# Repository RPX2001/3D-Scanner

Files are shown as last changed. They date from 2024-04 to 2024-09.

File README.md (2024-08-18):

# 3D Scanner Project

This repository contains the design and implementation of a 3D scanner using an ATmega328P microcontroller, NEMA 17 stepper motors, and stepper drivers. The goal of this project is to capture a point cloud of a 3D object, transmit the data to a computer as serial data, and map those points using software.

## Project Overview
Our 3D scanner project aims to design and build a machine capable of scanning an object and generating a 3D map of it. The scanner primarily comprises two parts: a linear Z-axis motion slider and a turntable. The object to be scanned is placed on the turntable, which rotates during scanning. After each full rotation, the Z-axis slider raises the ToF sensor slightly, and the process repeats. Distance measurements from the ToF sensor are sent to a PC in real-time via serial communication, stored in a .txt file, and used to generate a 3D point cloud map of the scanned object.

## Project Components
- **Microcontroller**: ATmega328P
- **Stepper Motors**: NEMA 17
- **Stepper Motor Drivers**: TB6600
- **ToF Sensor**: VL53L0X
- **Voltage Regulator**: LM7805
- **USB to Serial Converter**: CH340C
- **Turntable and Z-axis Slider**: Custom mechanical parts designed in SolidWorks

## Electronic Design

### Component Selection

- **Microcontroller (ATmega328P)**: Chosen for its reliability, compact size, and capability to handle multiple inputs efficiently. It is programmed via a USB connection using the CH340C IC.
- **Stepper Motors (NEMA 17)**: Selected for their high torque and compatibility with 12V power supply. Specifications include 76 oz*in torque, 1.8° step angle, and 1.68A/phase peak current.
- **Stepper Motor Drivers (TB6600)**: Supports a wide range of power inputs (9-42VDC) and can output 4A peak current. Features include speed and direction control, microstep settings, and high-speed optocoupler isolation.
- **ToF Sensor (VL53L0X)**: Provides accurate distance measurements for scanning.
- **Voltage Regulator (LM7805)**: Converts 12V input to a stable 5V output to power the microcontroller and sensor.

### PCB Design
The PCB design integrates the microcontroller, voltage regulator, stepper motor drivers, and USB to serial converter. SMD components are used to minimize space. The design includes necessary capacitors for the LM7805, signal routing for stepper motor control, and connectors for the ToF sensor and stepper motors.

## Mechanical Design
The mechanical design includes a 14cm diameter turntable and a Z-axis slider mechanism. Components such as smooth shafts, screw shafts, and couplers ensure precise linear motion. The enclosure houses the PCB, stepper drivers, and motors, providing a compact and durable structure.

## Software Implementation
### Arduino Code
The Arduino code controls the stepper motors and reads distance values from the ToF sensor. It uses direct port manipulation and register-level programming for efficient motor control.

### Functionality

1. **Object Placement:** The object to be scanned is placed on a turntable.
2. **Rotation and Scanning:** The turntable rotates the object while the distance sensor captures measurements along the Z-axis.
3. **Data Transmission:** The ATmega328P microcontroller collects the distance measurements and transmits the data to a computer via serial communication.
4. **Point Cloud Mapping:** Software on the computer receives the serial data and maps the points to create a 3D representation of the object.

### PCB 

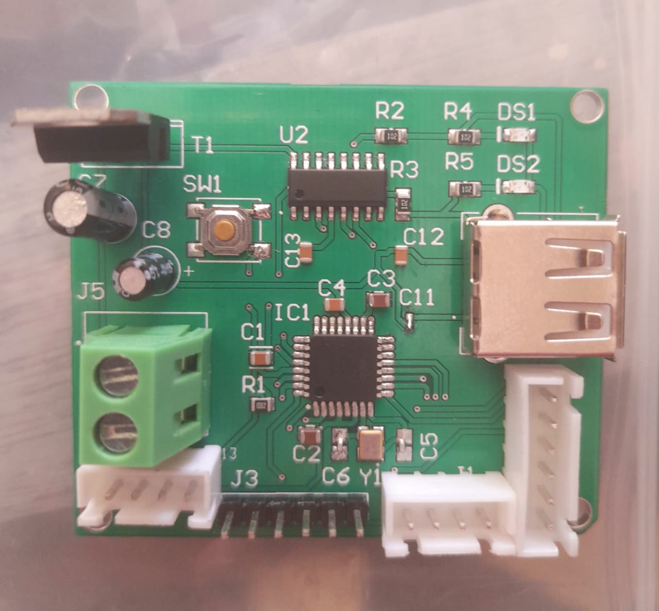
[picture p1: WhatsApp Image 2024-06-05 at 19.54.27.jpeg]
PCB


### Enclosure

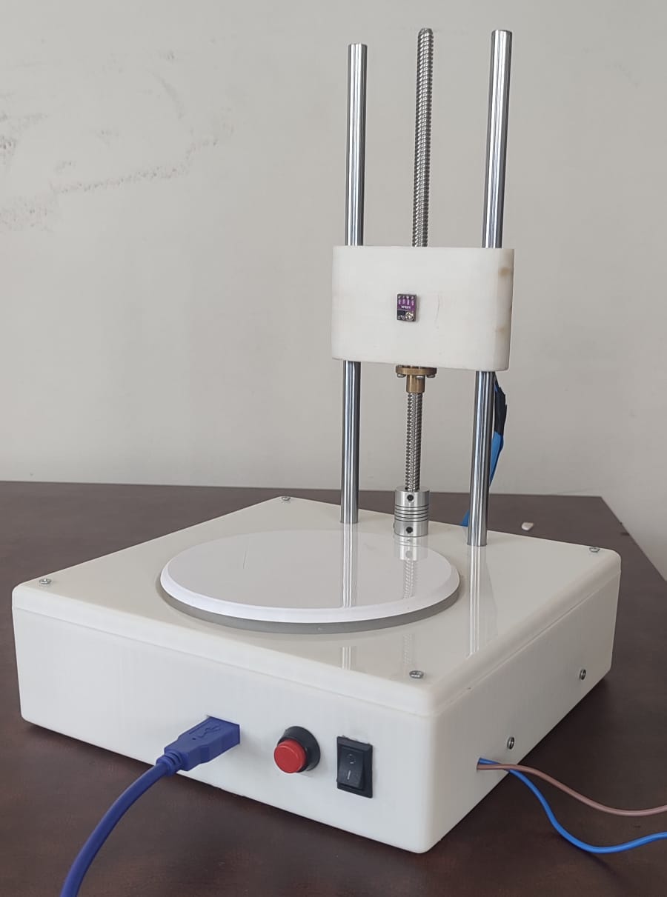
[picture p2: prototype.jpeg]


### System Integration

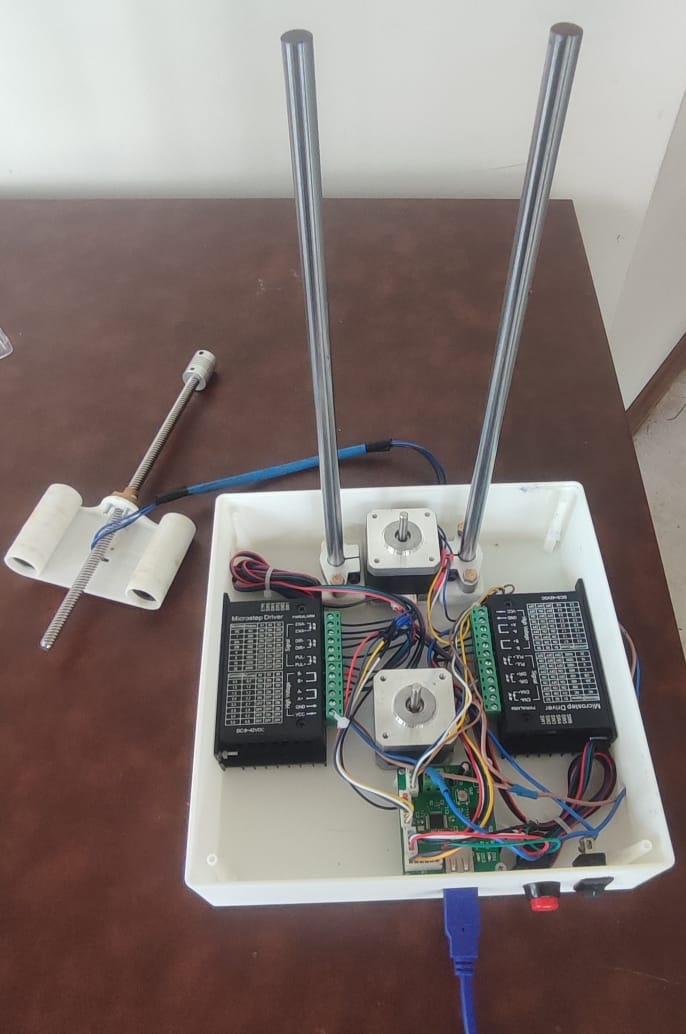
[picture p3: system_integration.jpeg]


## Contributors

- [Samudra Uduwaka](https://github.com/samudra-uduwaka)

## License

This project is licensed under the [MIT License](LICENSE).

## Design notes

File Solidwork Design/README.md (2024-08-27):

## Solidwork Design

The Solidwork design for our project, 3D Scanner is mainly comprised of 3 parts:

- Main Body
- Tray lid
- Turnable table
- Connector part

Used platform: Solidworks

All the sub main parts of the design are designed so that they are moldable for the large scale producability and, for the ease of testing we decided for 3D printing the parts.

Enclosure

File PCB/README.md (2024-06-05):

# PCB Design of the 3D scanner

This repository contains the design and implementation of a 3D scanner using an ATmega328P microcontroller, NEMA 17 stepper motors, and stepper drivers. The project aims to capture a point cloud of a 3D object and transmit the data to a computer as serial data for mapping those points using software.

### PCB 
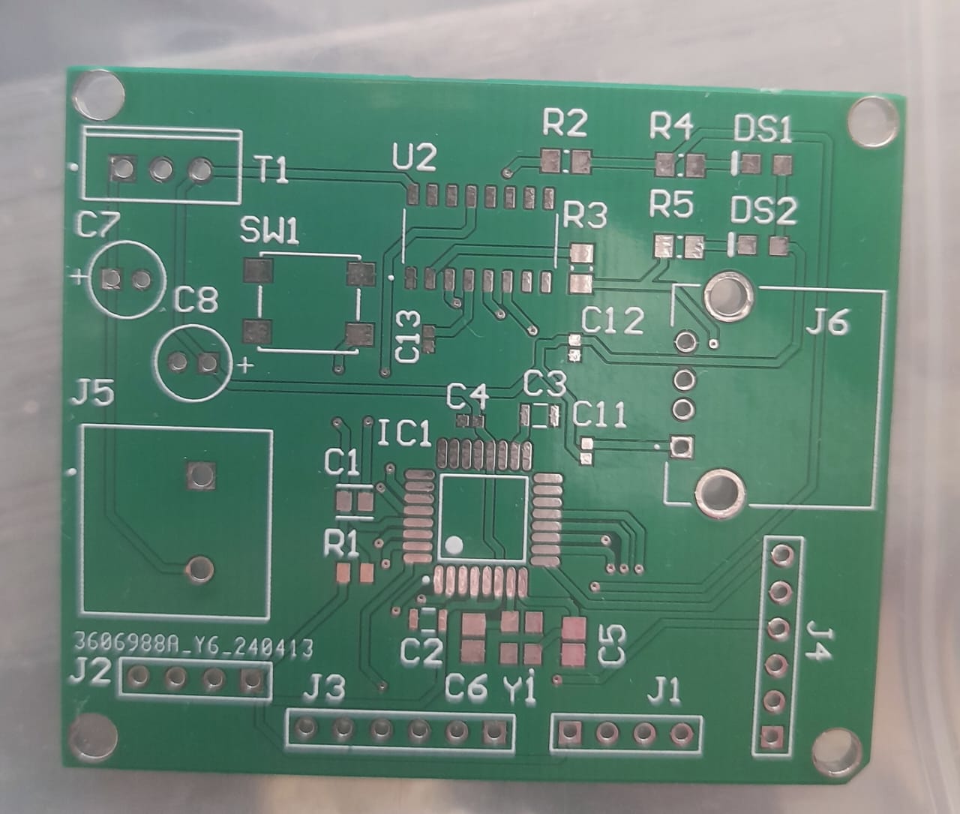
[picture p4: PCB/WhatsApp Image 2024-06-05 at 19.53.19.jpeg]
PCB


### Components

- **Microcontroller:** ATmega328P (SMD)
- **USB to Serial Chip:** CH340C
- **Stepper Motors:** NEMA 17
- **Stepper Drivers:** (Specify model, e.g., A4988 or DRV8825)
- **Distance Sensor:** ToF sensor (using SCL and SDA pins)
- **Mechanical Design:** Smooth and screw shafts for precision movement
- **PCB Layout:** Designed using SMD components
  
### Bill of Materials

| Comment | Description | Designator | Footprint | LibRef | Quantity |
|---|---|---|---|---|---|
| 0.1uF | Multilayer Ceramic Capacitor 0.1uF 10V 10% SMD 0805 T/R | C1 | FP-0805-L_2_0_0_1-W_1_25-IPC_C | CMP-14477-004636-2 | 1 |
| 10uF | Cap Ceramic 10uF 25V X7S 10% Pad SMD 0805 +125°C Automotive T/R | C2, C3 | FP-CGA4J-IPC_C | CMP-08246-001526-1 | 2 |
| 100nF | Chip Capacitor, 100nF, +/-10%, 16V, -55 to 125 degC, 0402 (1005 Metric) | C4, C11-C13| CAPC1050X55X23ML05T13 | CMP-2000-05439-1 | 4 |
| 10uF (Electrolytic)| Aluminum Electrolytic Capacitor, 10uF, +/-20%, 50V, -40 to 85 degC | C7, C8 | CAPPR55-200-1100X500X1200 | CMP-001-00025-7 | 2 |
| Green LED | Chip LED, Green, 2.2V, -40 to 85 degC, 2-Pin SMD, Pb-Free, Tape and Reel | DS1, DS2 | AVAG-HSMX-C170_V | CMP-2000-05062-1 | 2 |
| ATmega328P | 8-bit AVR Microcontroller, 32KB Flash, 1KB EEPROM, 2KB SRAM, 32-pin TQFP | IC1 | 32A_M | CMP-0095-00269-2 | 1 |
| Header 4-Pin  | Header, 4-Pin | J1, J2 | HDR1X4 | Header 4 | 2 |
| Header 6-Pin  | Header, 6-Pin | J3, J4 | HDR1X6 | Header 6 | 2 |
| Terminal Block| PC Terminal Block, Pitch 6.35 mm, 1 x 2 Position, Height 21.5 mm | J5 | PHOE-1714955_V | CMP-2000-05797-1 | 1 |
| USB Connector | USB 2.0 Interface, Type A | J6 | SAMTEC_USB-A-S-X-X-TH | USB-A-S-X-X-TH | 1 |
| 10k Resistor  | Chip Resistor, 10k Ohm, +/-1%, 125 mW, -55 to 155 degC, 0805 (2012 Metric)  | R1 | RESC2013X60X40LL15T20 | CMP-2001-04472-1 | 1 |
| 1k Resistor | Chip Resistor, 1k Ohm, +/-1%, 125 mW, -55 to 155 degC, 0805 (2012 Metric) | R2, R3, R4, R5 | RESC2013X60X35ML10T20 | CMP-2100-03671-1 | 4 |
| Switch | Push Button Switch | SW1 | WS-TASV_L6W6H2.5_4304x30258x6 | CMP-1455-00007-2 | 1 |
| 5V Regulator  | Positive Voltage Regulator, 5V, 1A, 0 to 125 degC, 3-Pin TO-220, RoHS, Tube | T1 | FAIR-TO-220-3 | CMP-2000-04937-1 | 1 |
| USB to Serial | USB to Serial Chip | U2 | SOIC127P600X180-16N | CH340C | 1 |
| Crystal | Quartz Crystal | Y1 | WE-XTAL_CFPX-180 | CMP-03913-116876469-1 | 1 |

### Block Diagrams and Schematics

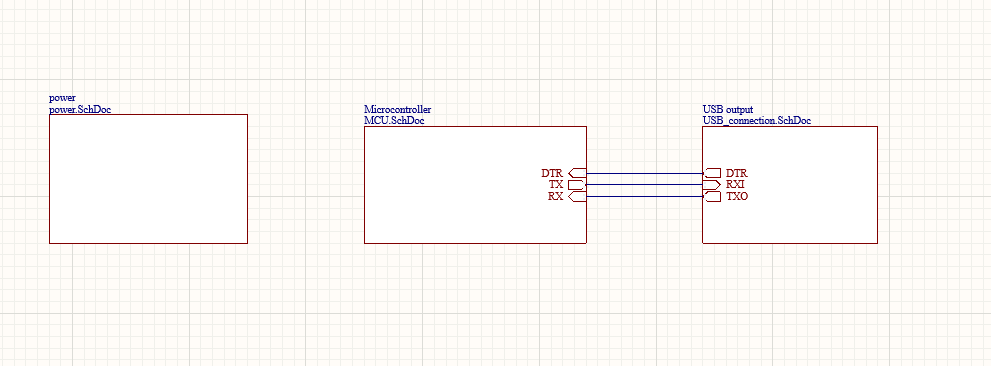
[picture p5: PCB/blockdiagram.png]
Functional Block Diagram


### Microcontroller Unit

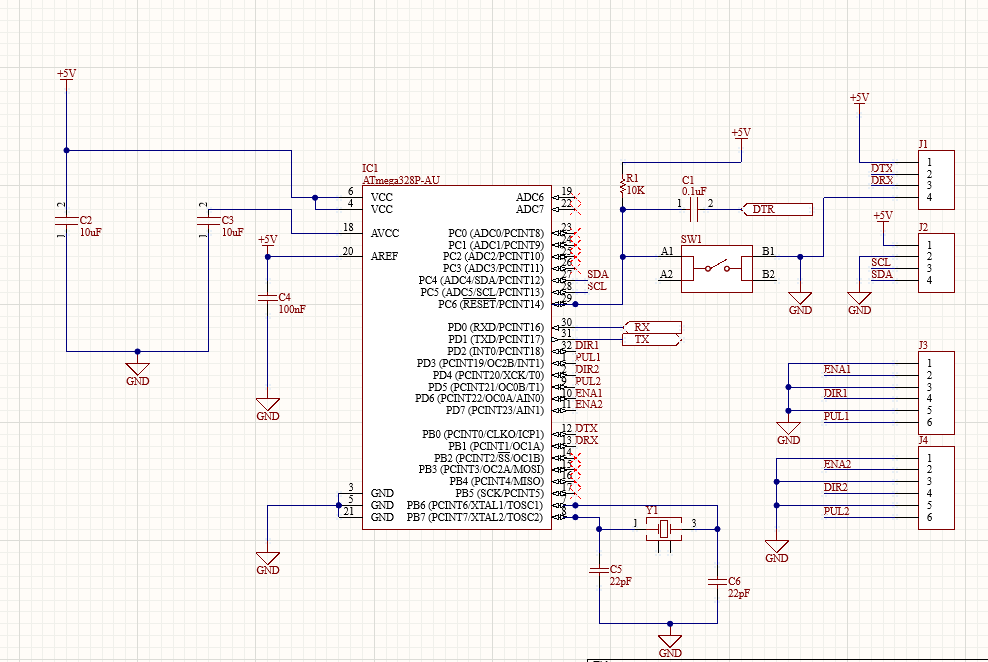
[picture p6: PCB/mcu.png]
microcontroller unit


### USB Connection

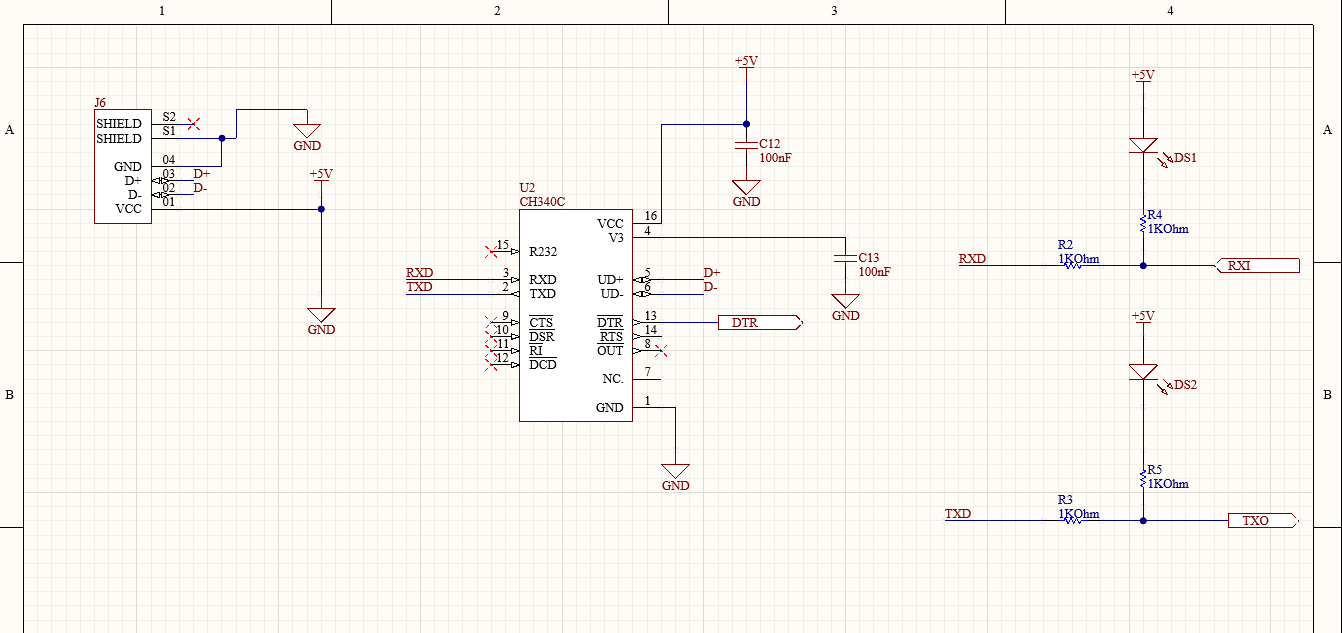
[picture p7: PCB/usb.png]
USB


### Power Regulation

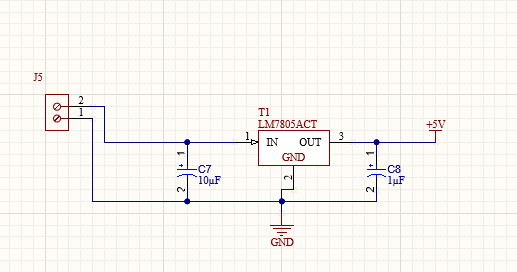
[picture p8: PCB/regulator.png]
Power


## PCB Layout

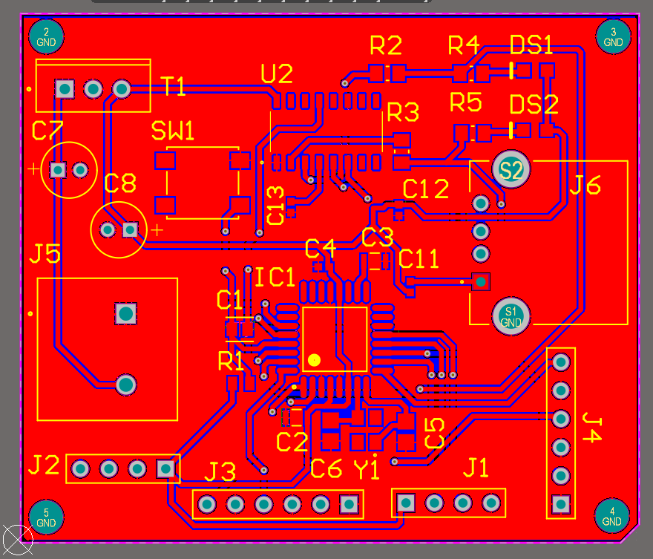
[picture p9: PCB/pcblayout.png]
PCB Layout


## 3D Design

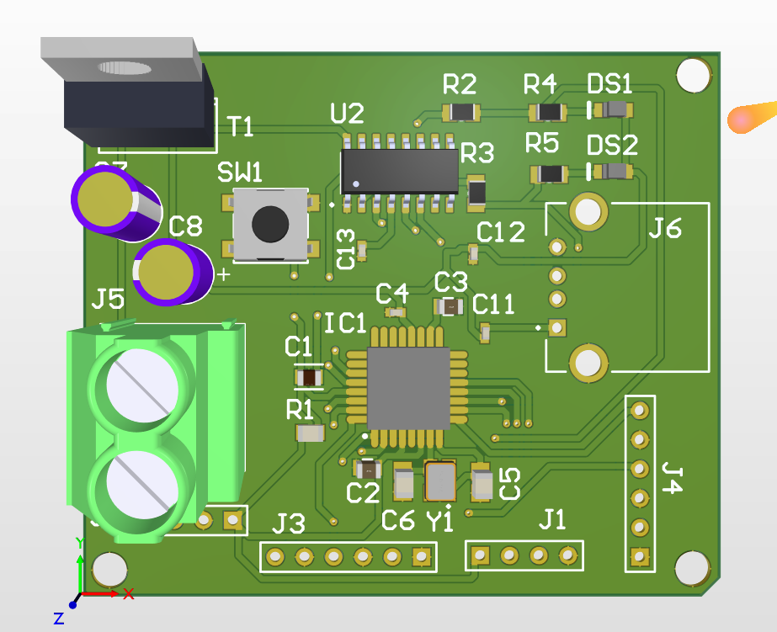
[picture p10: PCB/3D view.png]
3D design


## License

This project is licensed under the MIT License. See the [LICENSE](LICENSE) file for details.

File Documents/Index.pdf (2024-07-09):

Index | Name | Signature
210451U | Pathirana R. P. S.
210663V | Uduwaka S. S.

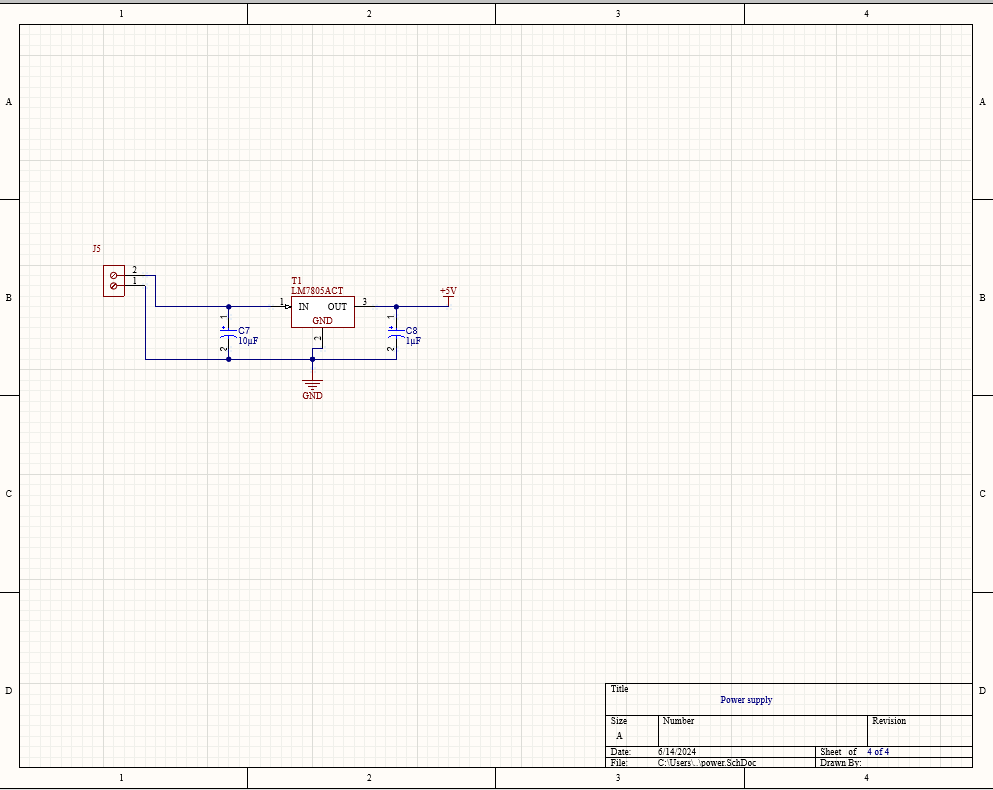
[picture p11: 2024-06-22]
power.png

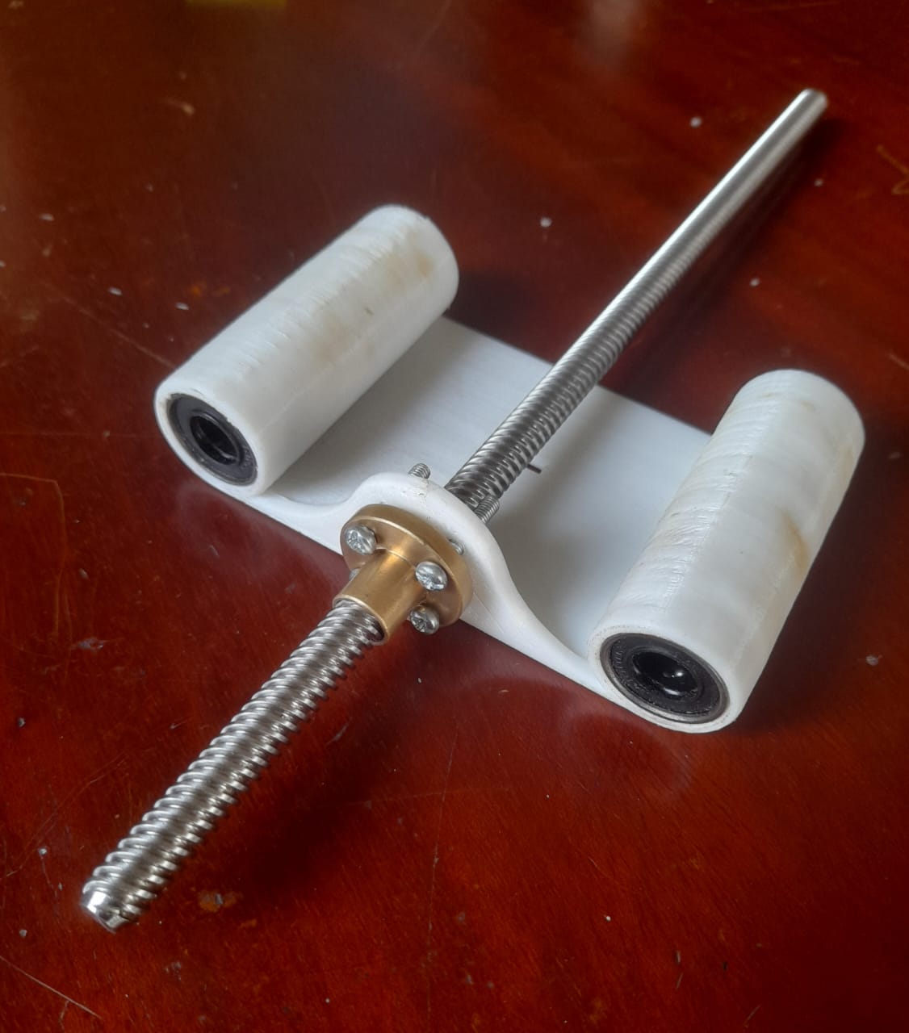
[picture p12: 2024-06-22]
connector.jpeg

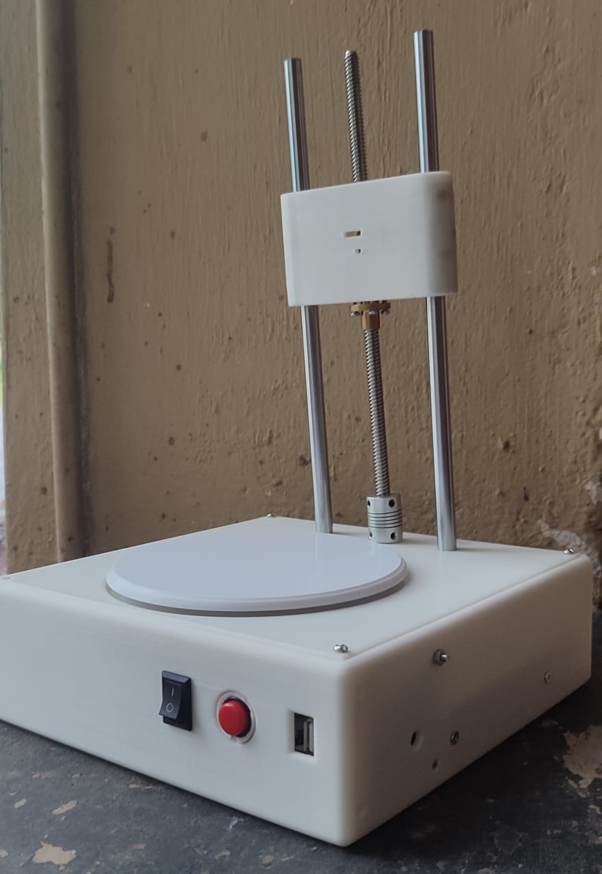
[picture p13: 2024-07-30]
final.jpeg

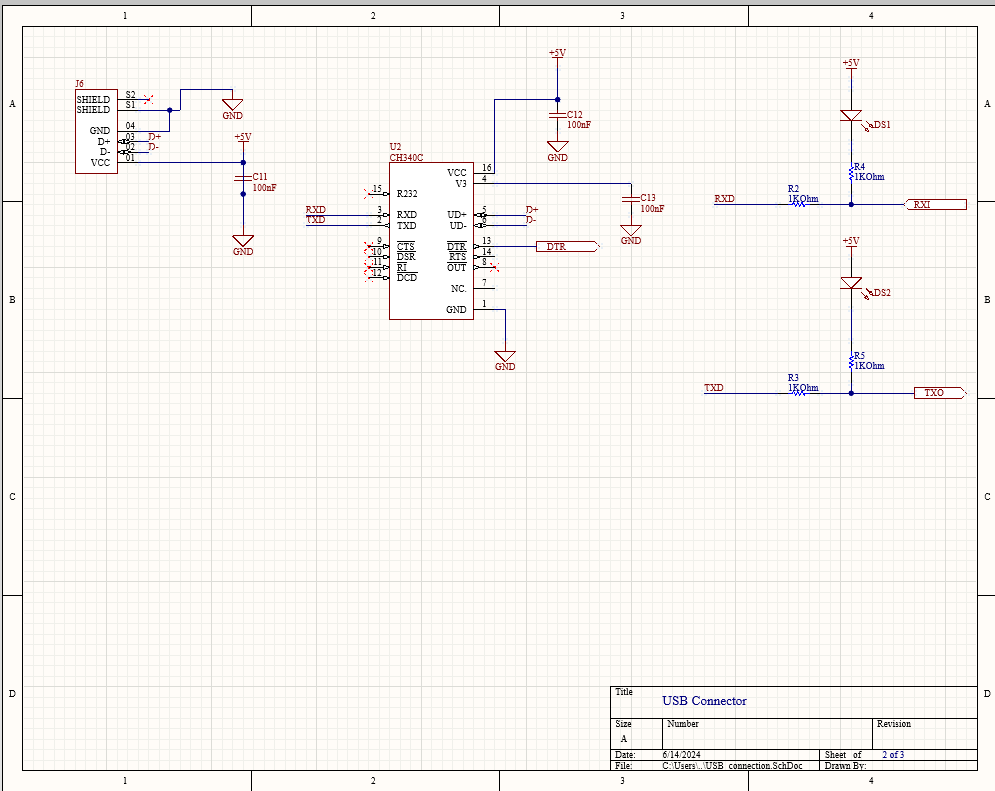
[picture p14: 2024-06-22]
usb.png

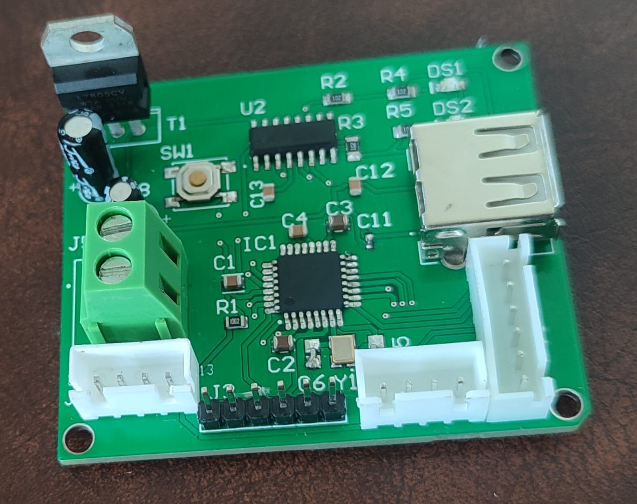
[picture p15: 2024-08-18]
pcb.jpeg

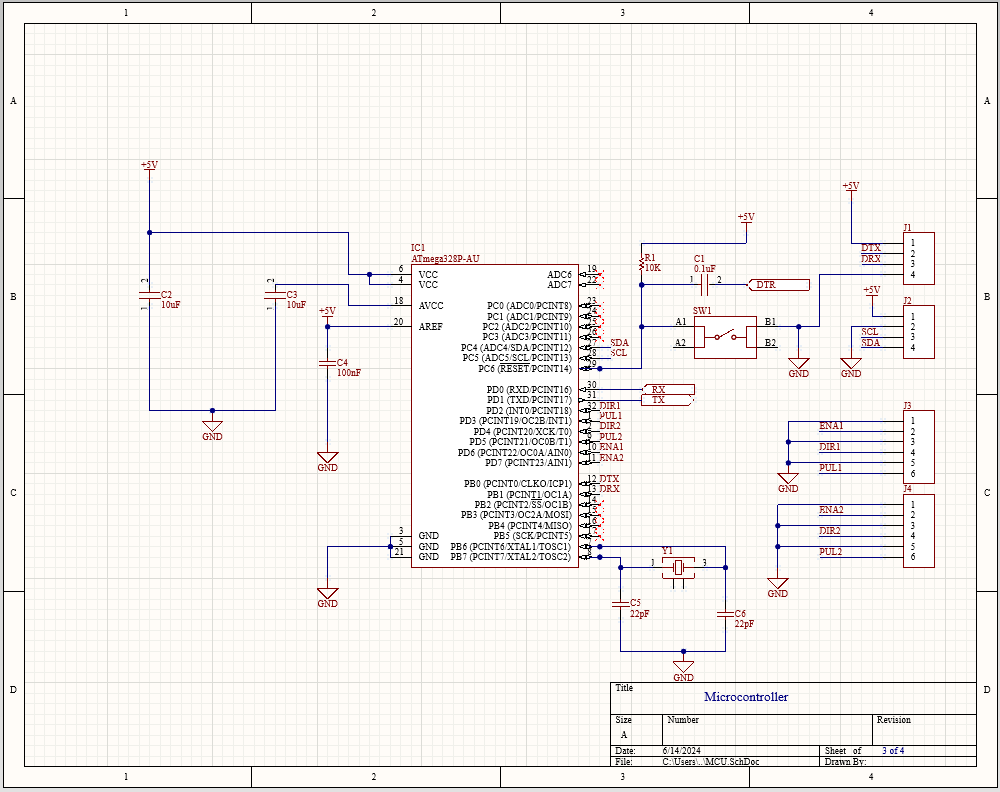
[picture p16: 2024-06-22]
mcu.png

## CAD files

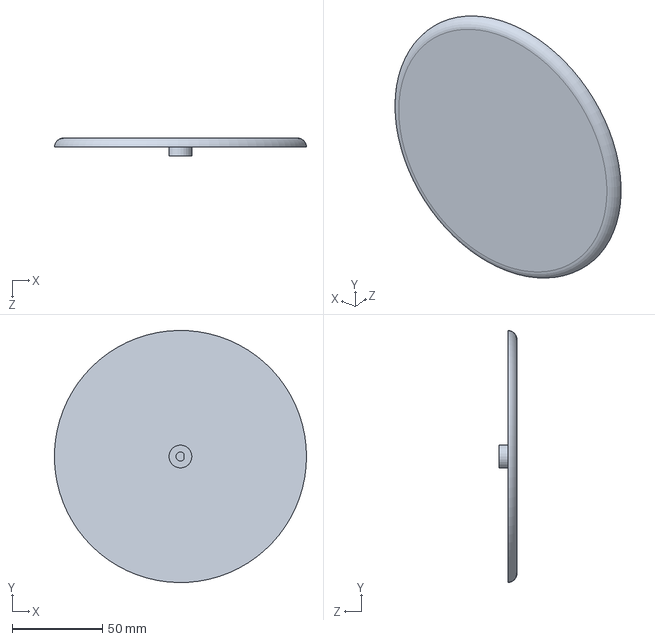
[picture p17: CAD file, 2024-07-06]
Solidwork Design/Part4_Assem2.SLDPRT
139.9 x 140.0 x 10.0 mm

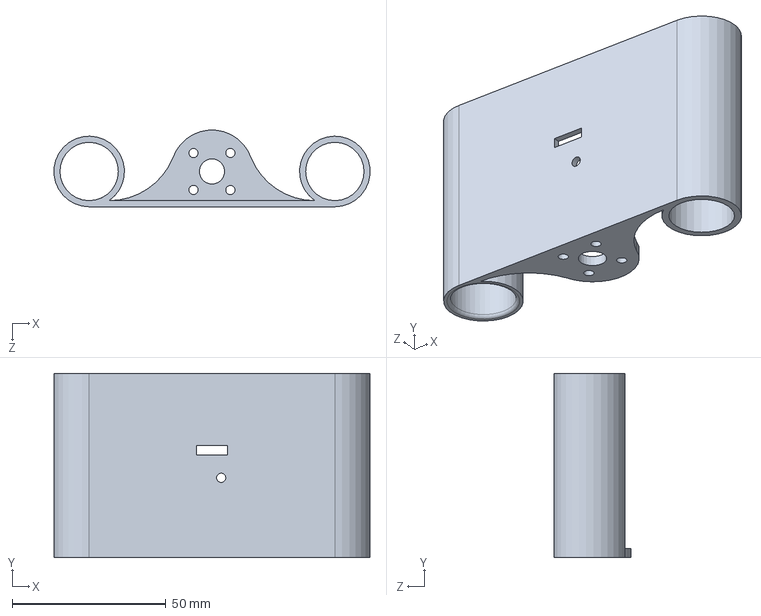
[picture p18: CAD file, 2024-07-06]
Solidwork Design/Part1 (1).SLDPRT
102.9 x 60.0 x 24.9 mm

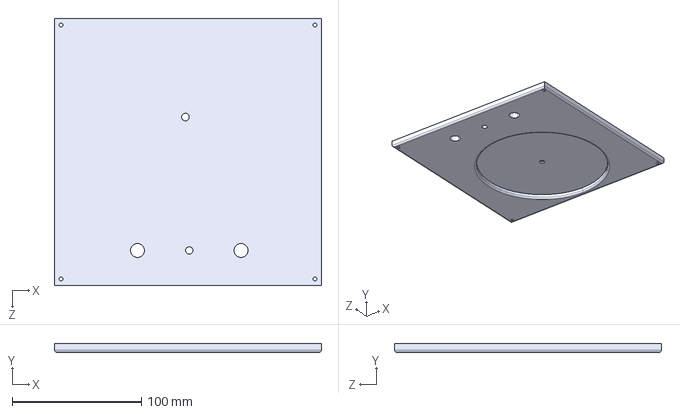
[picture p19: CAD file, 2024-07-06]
Solidwork Design/TrayLid.STEP
206.2 x 7.00 x 206.2 mm

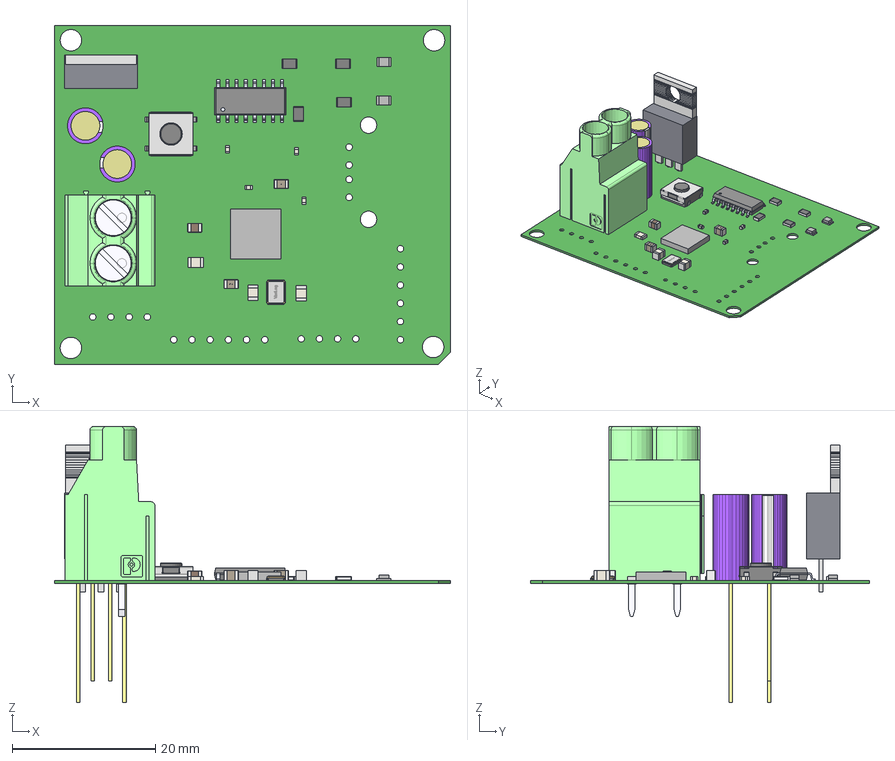
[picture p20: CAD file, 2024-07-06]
Solidwork Design/3Dscanner.step
55.2 x 47.2 x 38.5 mm
Extruded x 73
Pins
Cover
base
top_cover
Mid_Body x 4
Open_CASCADE_STEP_translator_6.8_3.2.1 x 8
Mark x 4
mkds_5-2-6.35
side x 4
TDK_Logo x 2
Terminals
Electrode
Taiyo

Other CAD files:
Solidwork Design/TrayLid.SLDPRT

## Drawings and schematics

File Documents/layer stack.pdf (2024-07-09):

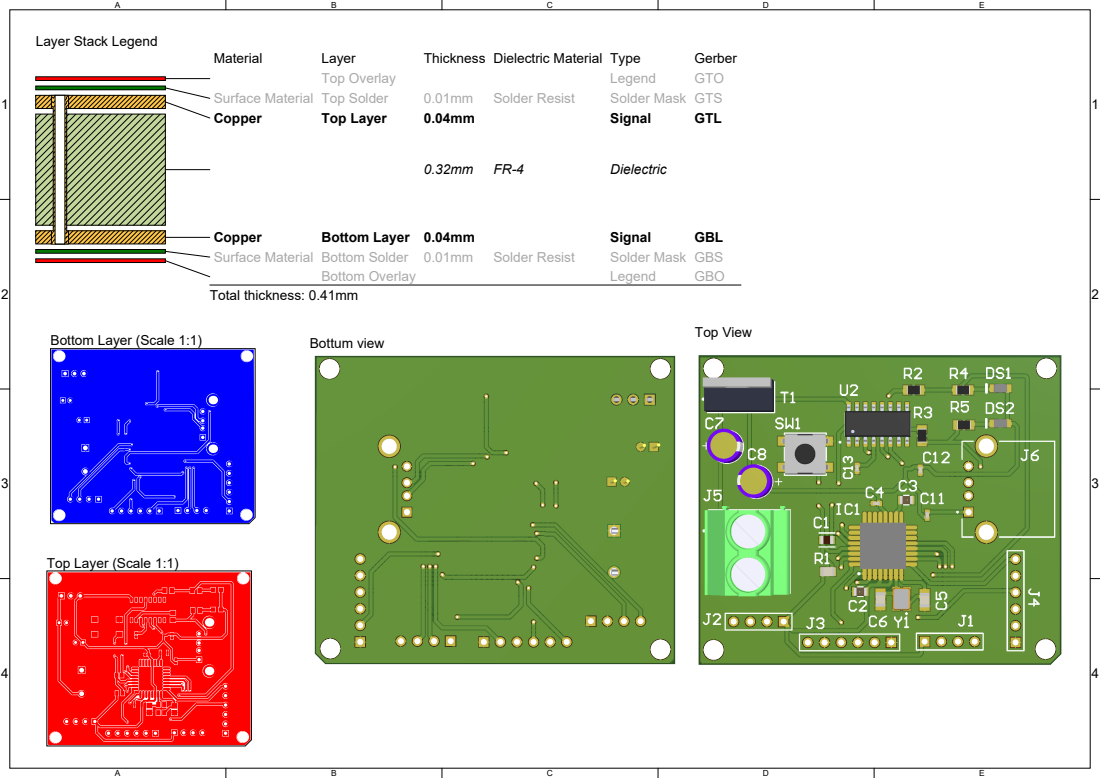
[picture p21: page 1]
Material; Layer; Thickness Dielectric Material Type; Gerber; Top Overlay; Legend; GTO; Surface Material Top Solder; Solder Resist; Solder Mask GTS; Copper; Top Layer; Signal; GTL; Dielectric; Bottom Layer 0.04mm; GBL; Surface Material Bottom Solder 0.01mm; Solder Mask GBS; Bottom Overlay; GBO; Total thickness: 0.41mm; Bottom Layer (Scale 1:1); Bottum view; Top View

Layer Stack Legend

Top Layer (Scale 1:1)

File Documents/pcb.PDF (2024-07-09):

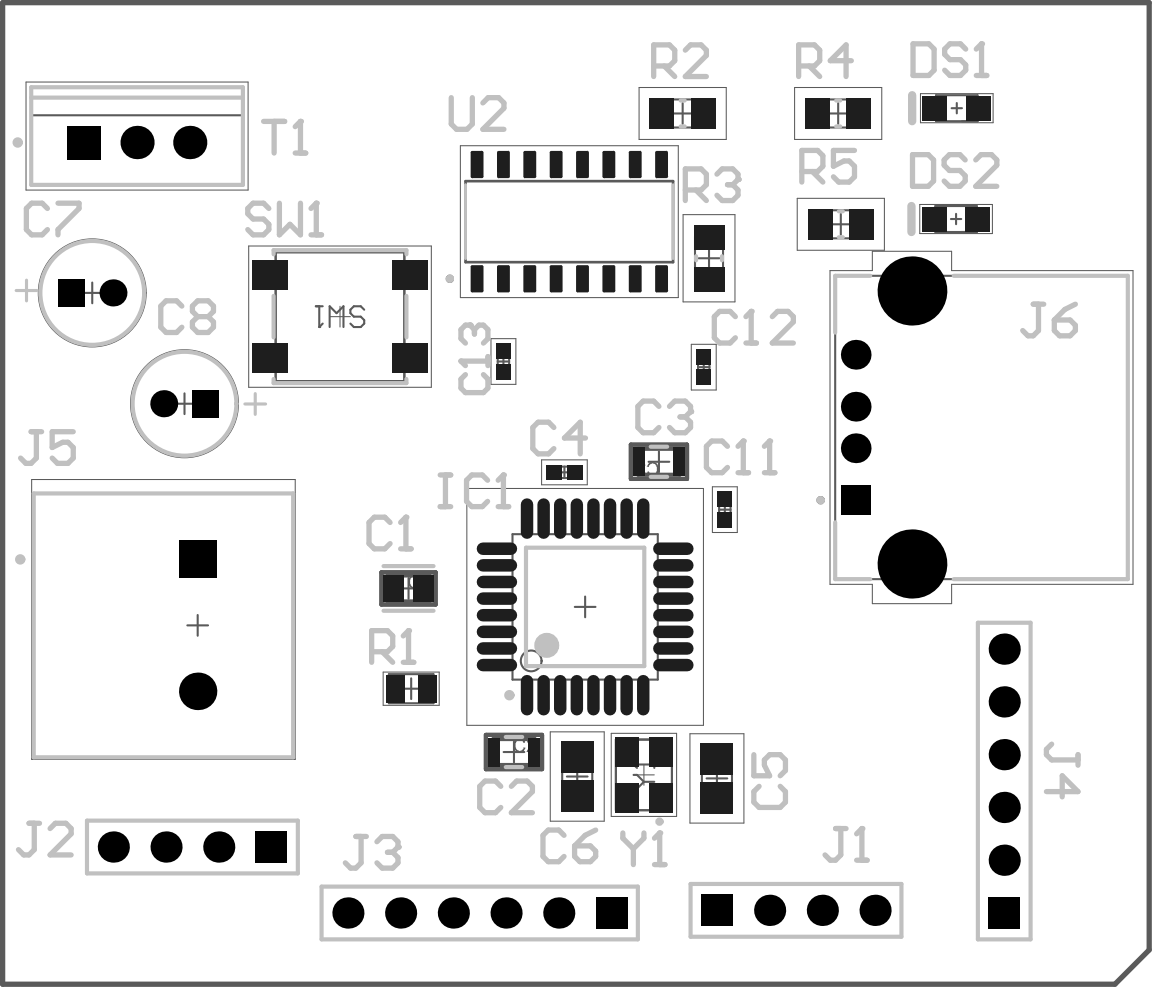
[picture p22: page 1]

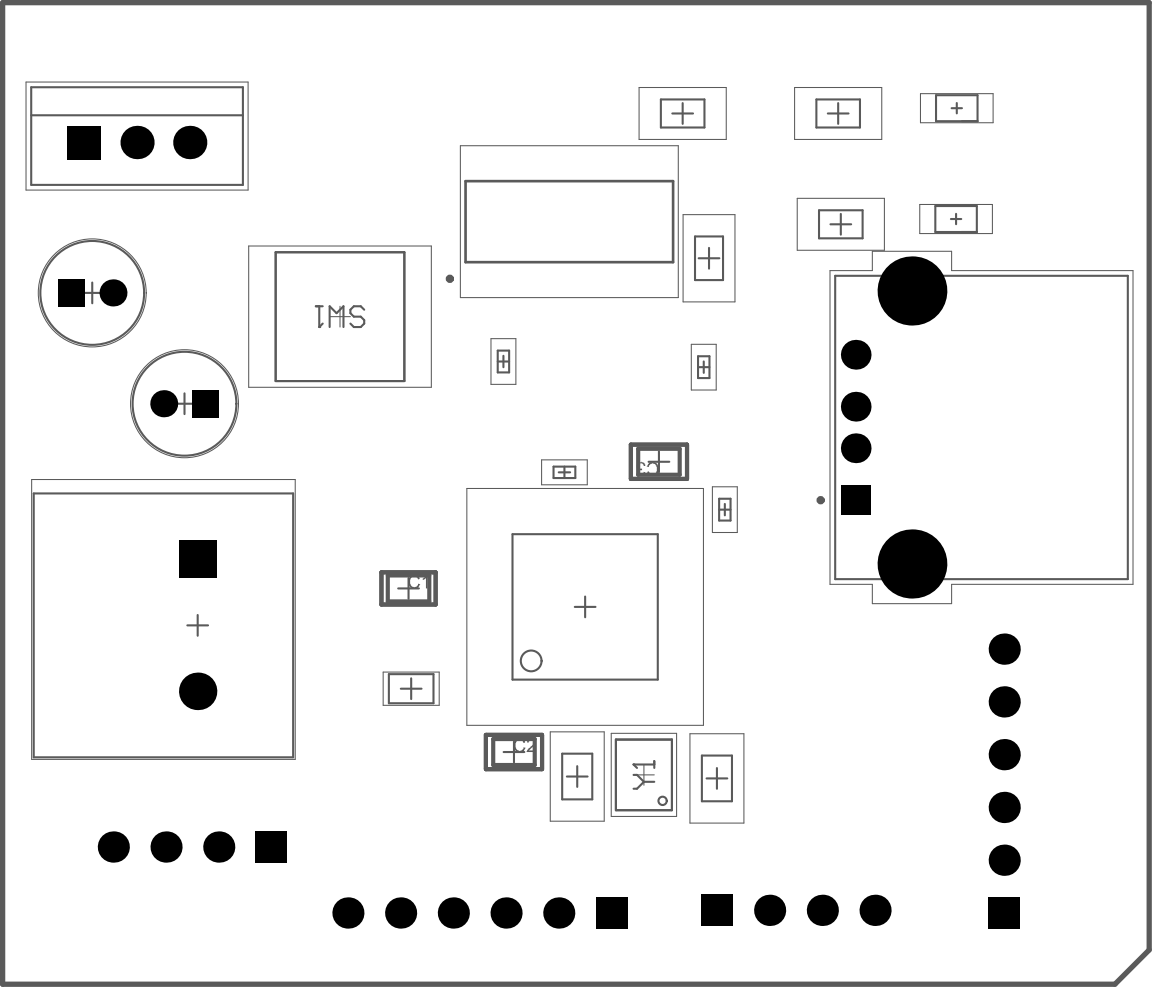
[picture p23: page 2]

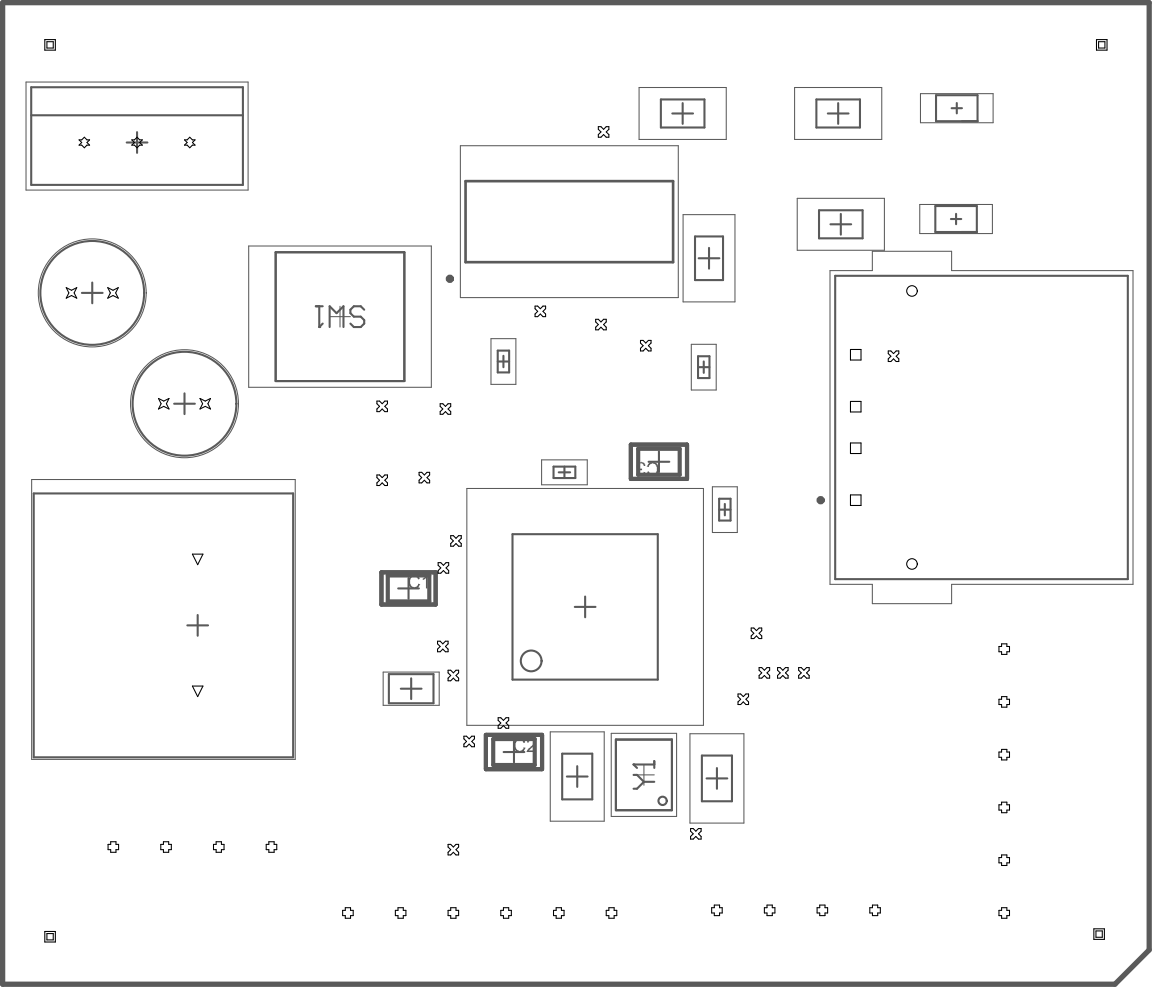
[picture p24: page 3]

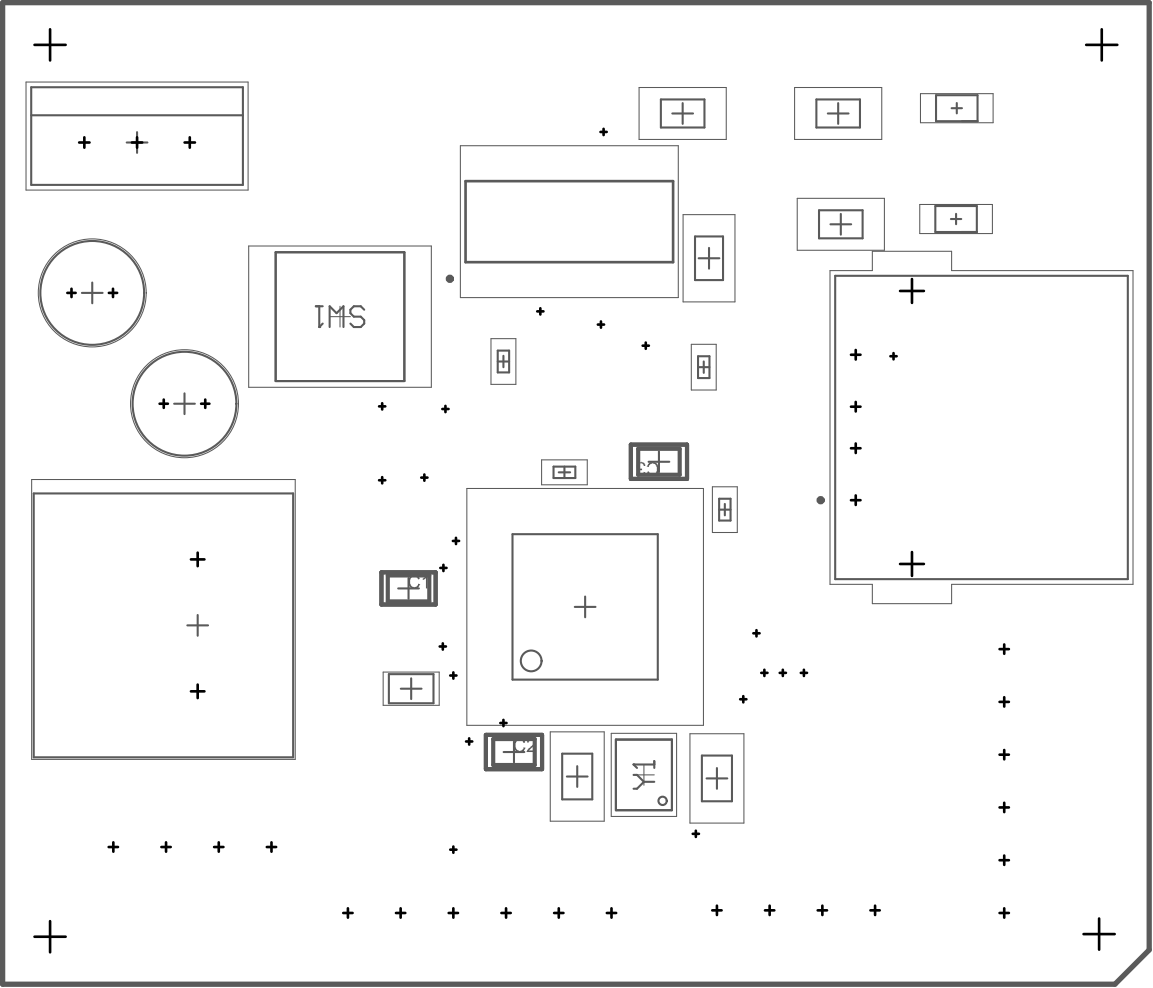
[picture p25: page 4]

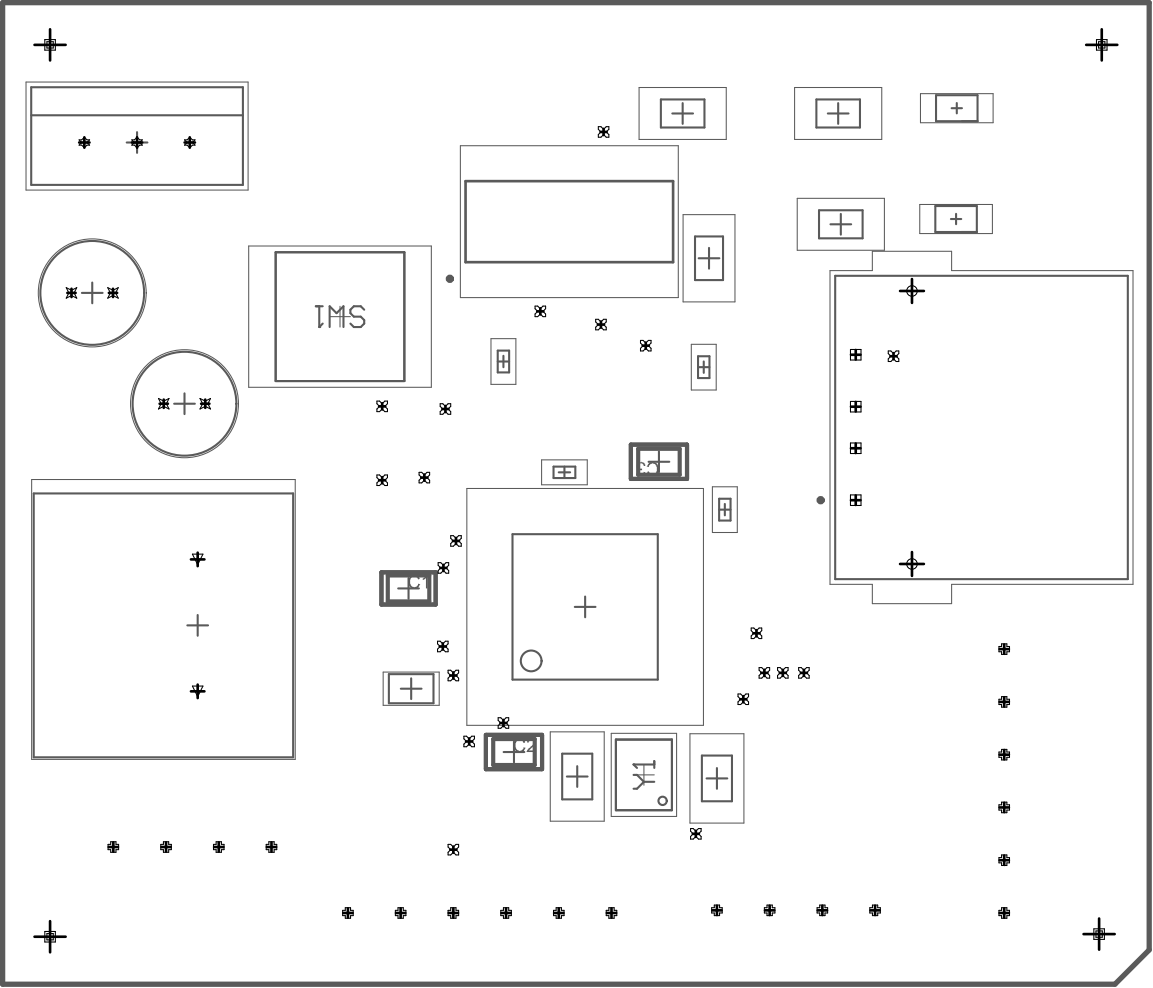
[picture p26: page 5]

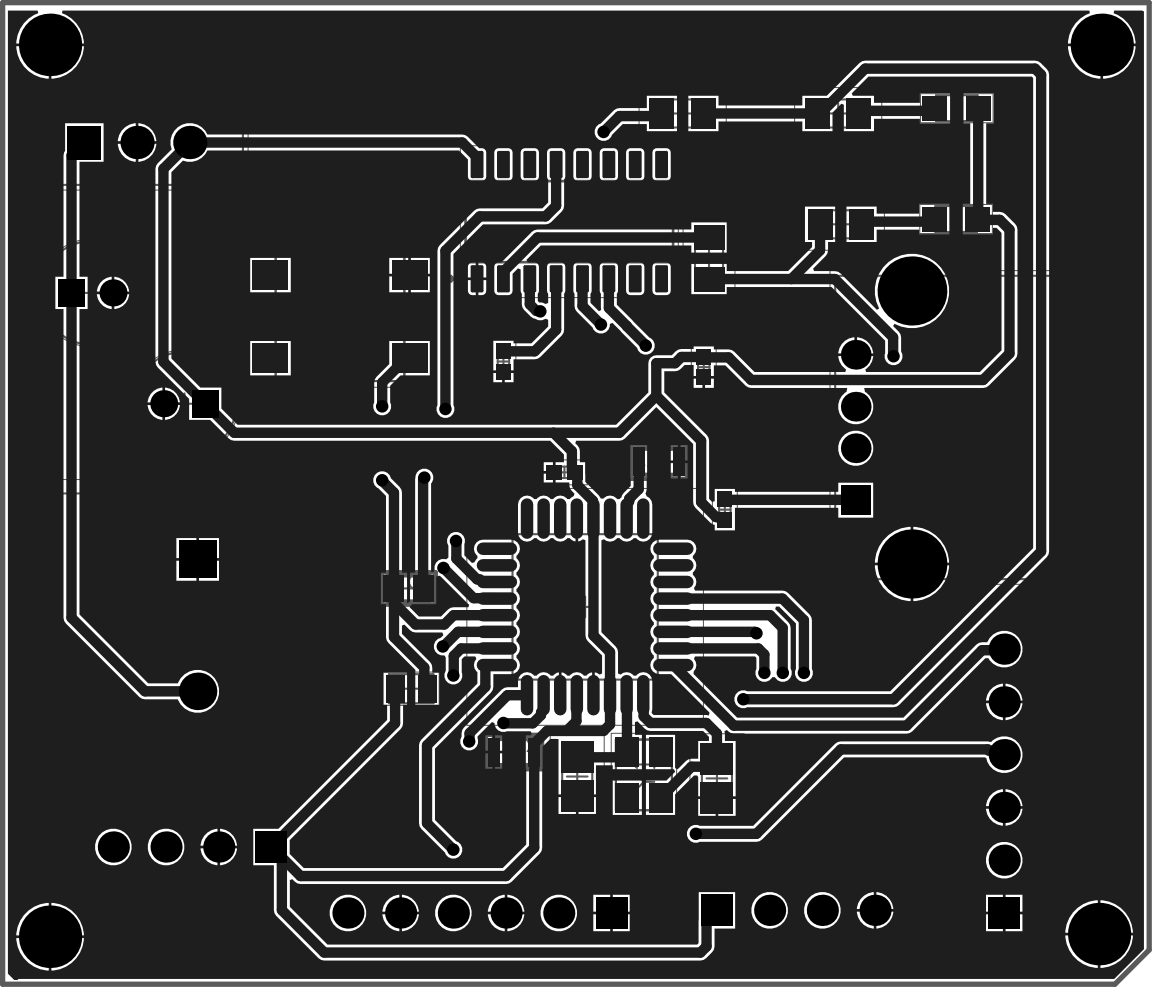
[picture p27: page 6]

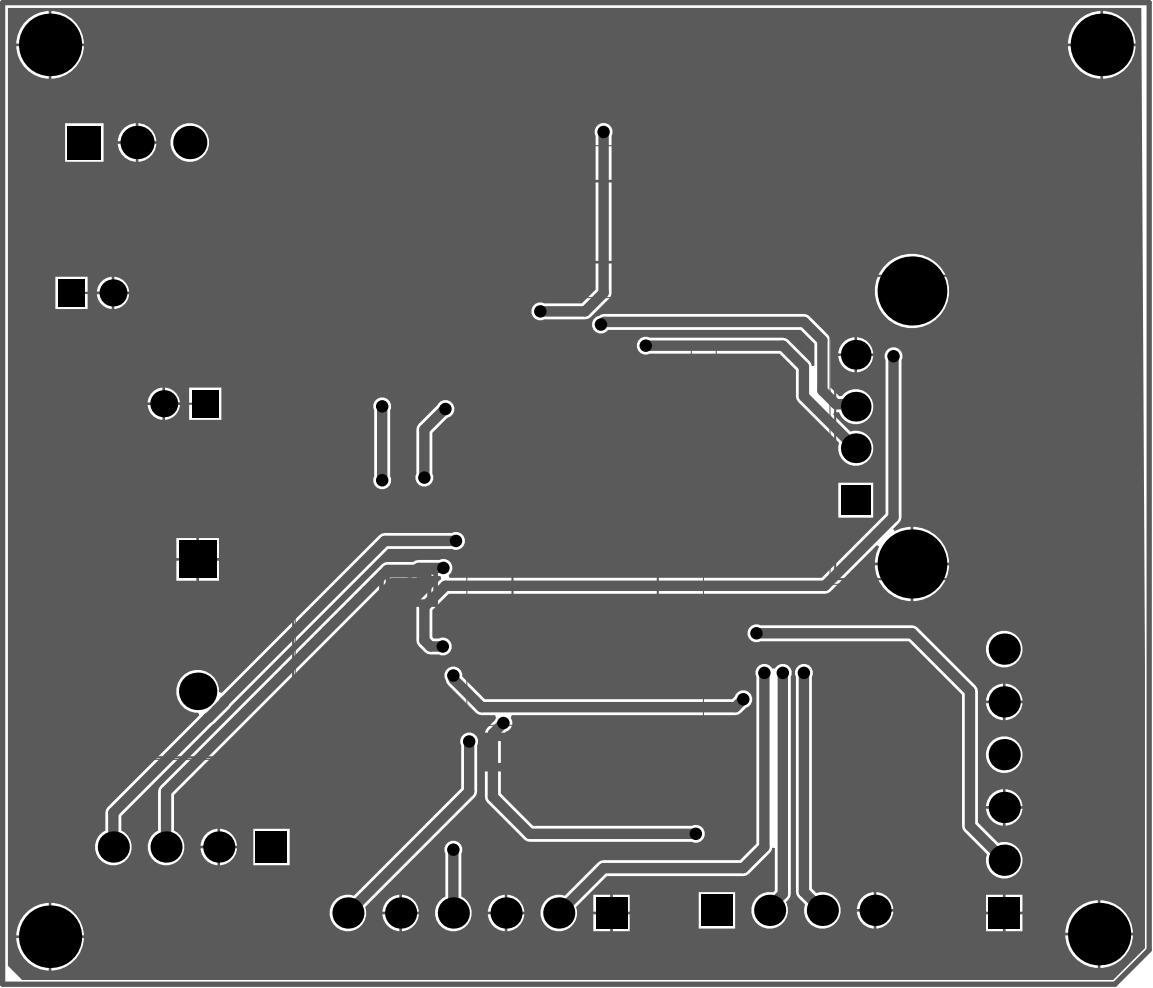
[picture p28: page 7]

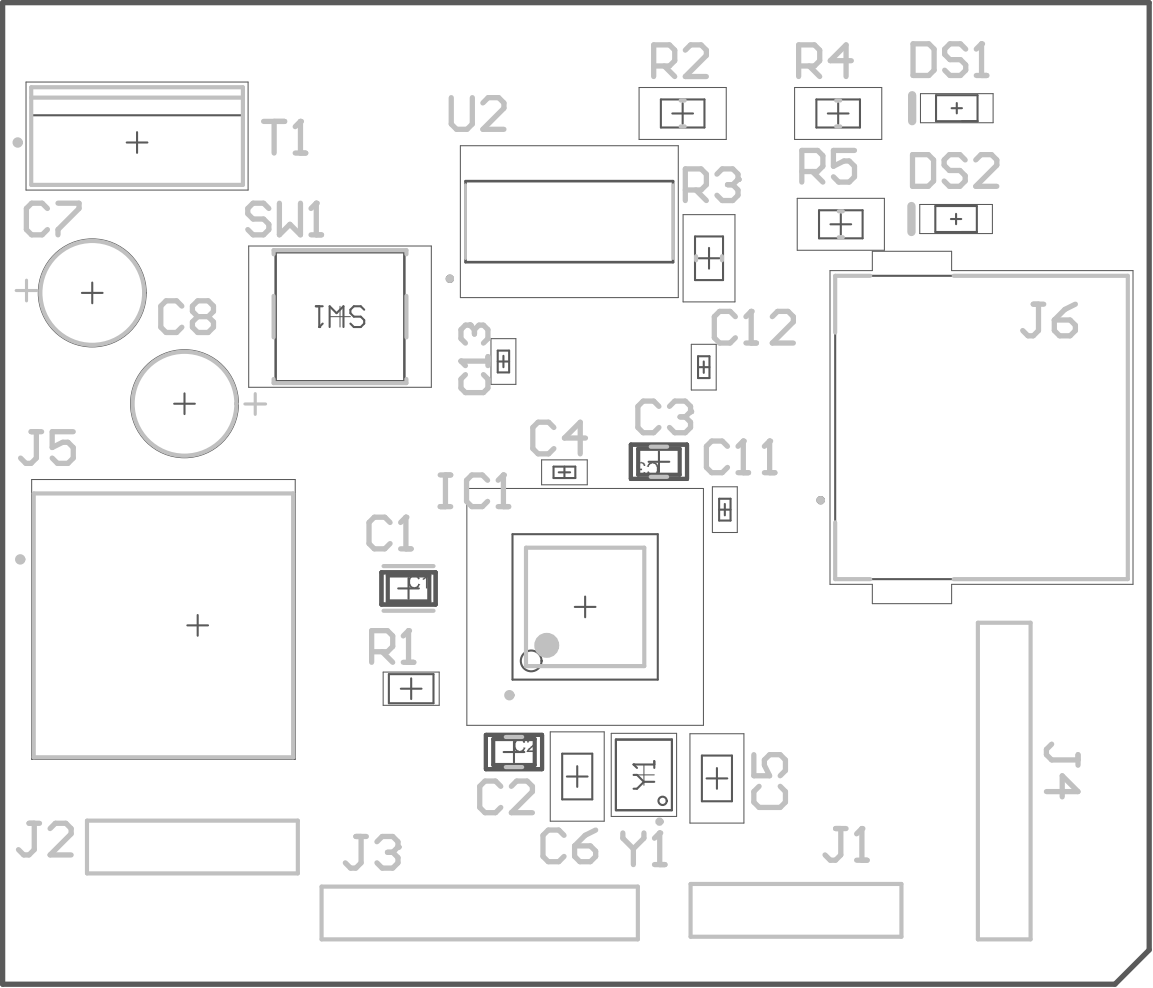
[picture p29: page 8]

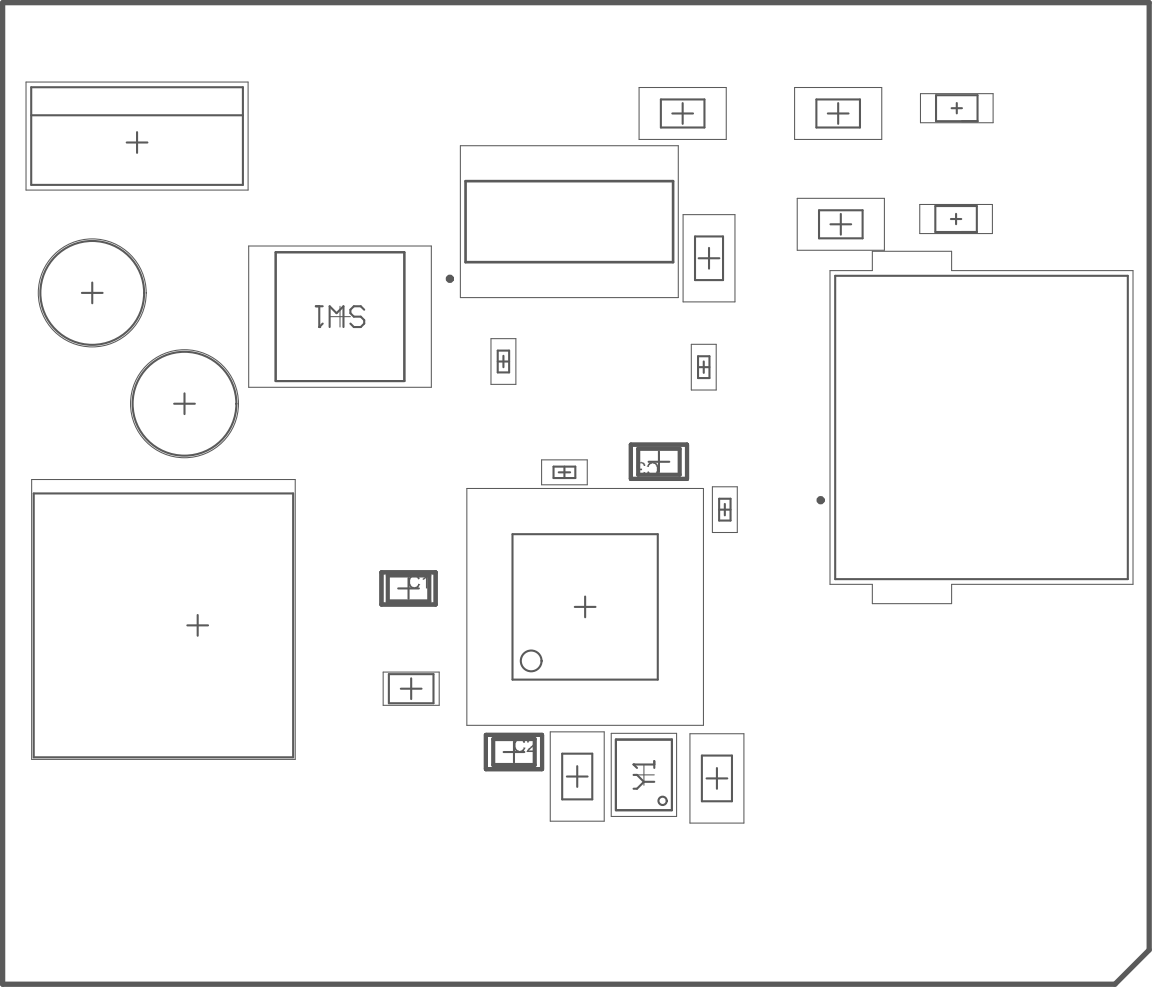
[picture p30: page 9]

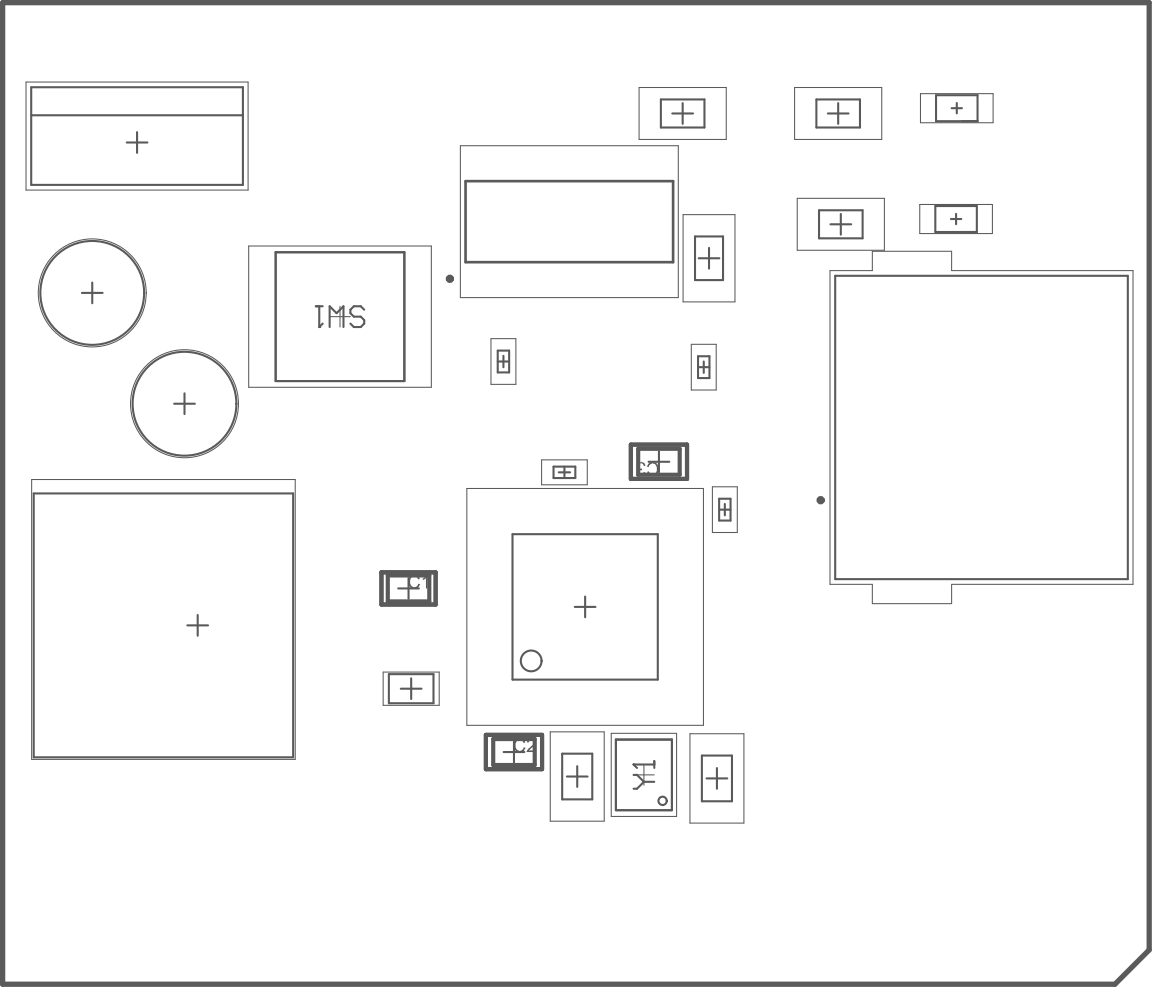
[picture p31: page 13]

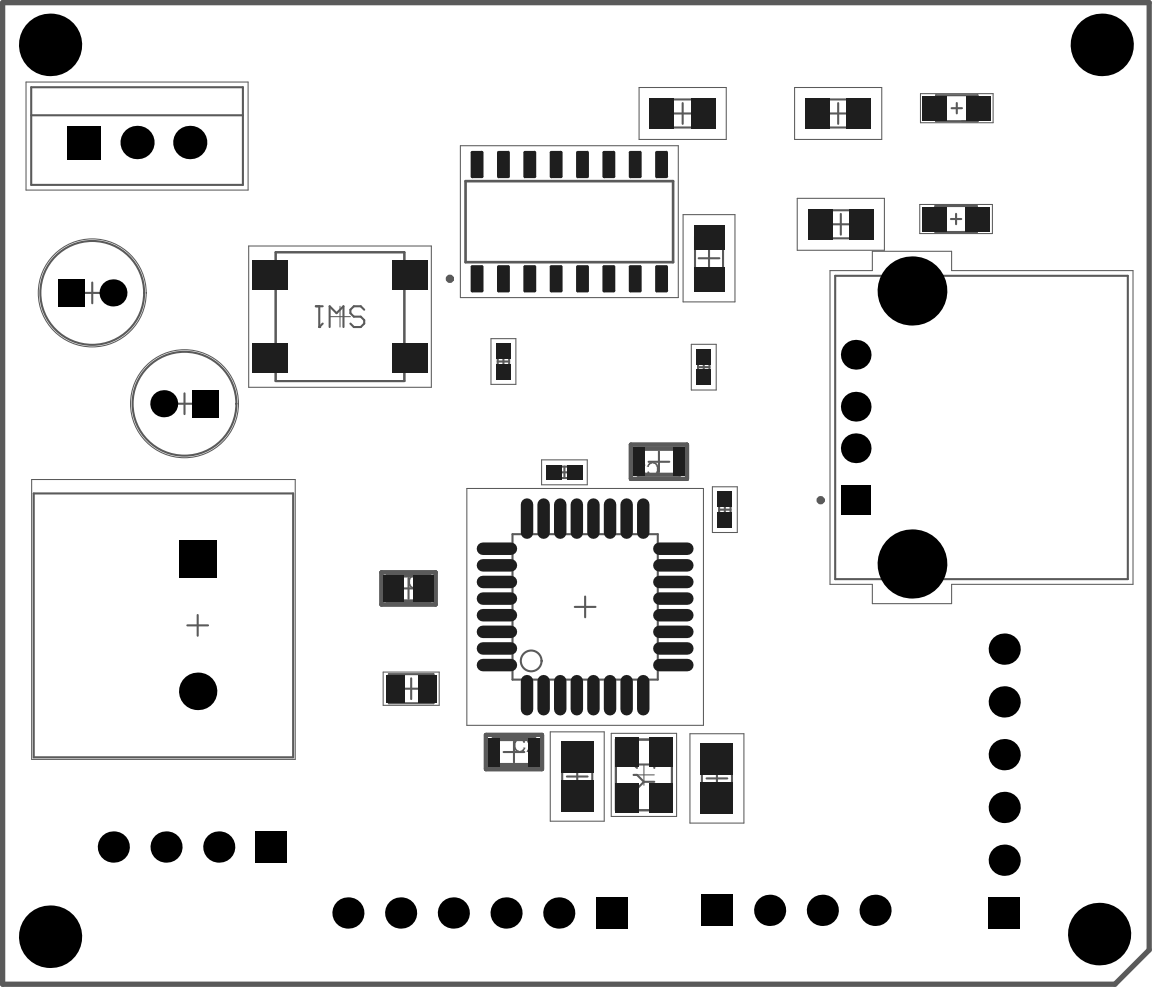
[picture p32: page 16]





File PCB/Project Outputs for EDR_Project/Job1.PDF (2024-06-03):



1 2
1 3



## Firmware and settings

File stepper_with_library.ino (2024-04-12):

#include <AccelStepper.h>

// Define stepper motor connections:
#define dirPin 2
#define stepPin 3

// Create a new instance of the AccelStepper class:
AccelStepper stepper(AccelStepper::DRIVER, stepPin, dirPin);

void setup() {
  // Set the maximum speed and acceleration:
  stepper.setMaxSpeed(1000);     // Adjust the speed as needed
  stepper.setAcceleration(500);  // Adjust the acceleration as needed

  // Set the spinning direction CW/CCW:
  stepper.setDirection(HIGH);

  // Set initial speed and position:
  stepper.setSpeed(500);  // Adjust the speed as needed
  stepper.setCurrentPosition(0);
}

void loop() {
  // Run the stepper motor continuously:
  stepper.runSpeed();
}

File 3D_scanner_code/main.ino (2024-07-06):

//main function

#include <avr/io.h>
#include "delay.h"
#include "uart.h"
#include "TWI.h"
#include "ToF.h"
#include "stepper.h"

int main(){
  init_uart();
  i2c_init();
  vl53l1x_init();
  init_stepper();
  DDRD |= (1<<DDD4);  //pin PD5 output - z_dir

  while(1){
    
    //trans_string("Distance: ");
    //delay_ms(100);


    uint8_t vert_distnce = 10;   /*max Z axis distance*/
    uint8_t z_steps = 200;  // z steps per rotation
    uint32_t z_counts = (200/1*vert_distnce)/z_steps;  //total z_counts ntil return home
    uint8_t theta_counts = 200;
    
    PORTD &= (~(1<<PORTD4)); // z_dir LOW
    for(uint32_t j=0;j<z_counts;j++)
    {
      for(uint8_t i=0; i<theta_counts;i++)
      {
        rotate_tmotor(1);   //start rotate turn table
        //double sense_distance = 0; //reset distance measurement
        vl53l1x_measure_distance();
        uint16_t distance = vl53l1x_read_distance();
        trans_num(distance);
        trans_string("\n");
        
      }
      rotate_zmotor(z_steps); //start rotating z axis motor
      delay_ms(1000);
      //serial print(9999);
      trans_num(9999);
      trans_string("\n");
    }
    PORTD |= (1<<PORTD4); // move z to home
    delay_ms(10); //delay 10ms
    for(uint32_t k=0;k<z_counts;k++){
      rotate_zmotor(z_steps);
      delay_ms(10);
    }

  }
  return 0;
}

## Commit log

2024-06-03 all pcb files and coding files
    [EDR_Project.PrjPcb, MCU.SchDoc, Power.SchDoc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]
2024-06-03 pcb ss
2024-06-05 pcb design
2024-07-06 final solidwork design files
    [3Dscanner.step, Part1 (1).SLDPRT, Part4_Assem2.SLDPRT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]
2024-07-30 printed parts
2024-08-18 final prototype
